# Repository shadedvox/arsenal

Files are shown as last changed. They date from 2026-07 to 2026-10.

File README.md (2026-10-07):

# Arsenal

A 6-DOF robotic arm built around a custom STM32 motor controller, closed-loop steppers, and a distributed ROS control stack. The project moves through four stages: electronics, mechanical build, firmware/control integration, and final assembly with the end effector.

---

## Stage 1 — Voxboard (electronics)

Voxboard is a custom 4-layer PCB motor controller built to drive all six joints of the arm from a single board. It replaces an earlier ESP32 + 28BYJ-48 stepper setup with a proper closed-loop system capable of real position feedback and real-time multi-axis control.

**Core architecture**
- STM32F446RET6 (LQFP64, 180MHz Cortex-M4 with FPU) handles all real-time motor control
- Raspberry Pi 3B+ runs inverse kinematics (ikpy) and talks to the STM32 over UART
- 3x TMC2209 drivers for the NEMA17 motors at roll, pitch, and yaw
- 3x TMC5160 drivers for the NEMA23 motors at elbow, base and shoulder
- 10 to 20:1 cycloidal gearbox on every joint, with an MT6835 absolute magnetic encoder at each gearbox output shaft for true closed-loop position feedback, no homing required on power-up

**Connectivity**
- CAN (for the end-effector node), USB, dual SPI (encoders + TMC5160s), triple UART (TMC2209s + RPi), I2C, SWD for debug

**Power**
- Single 24V input via XT60, reverse-polarity and surge protected, stepped down to 5V (buck) and 3.3V (LDO) for logic
- USB VBUS backup path with ideal-diode OR-ing, so the board can run off USB power alone for debug/bring-up

**Project Files & Schematics :** [\Stage1 - STM\voxboard](https://github.com/shadedvox/arsenal/tree/main/Stage1%20-%20STM/voxboard)

**Status: design completed - fabrication pending**

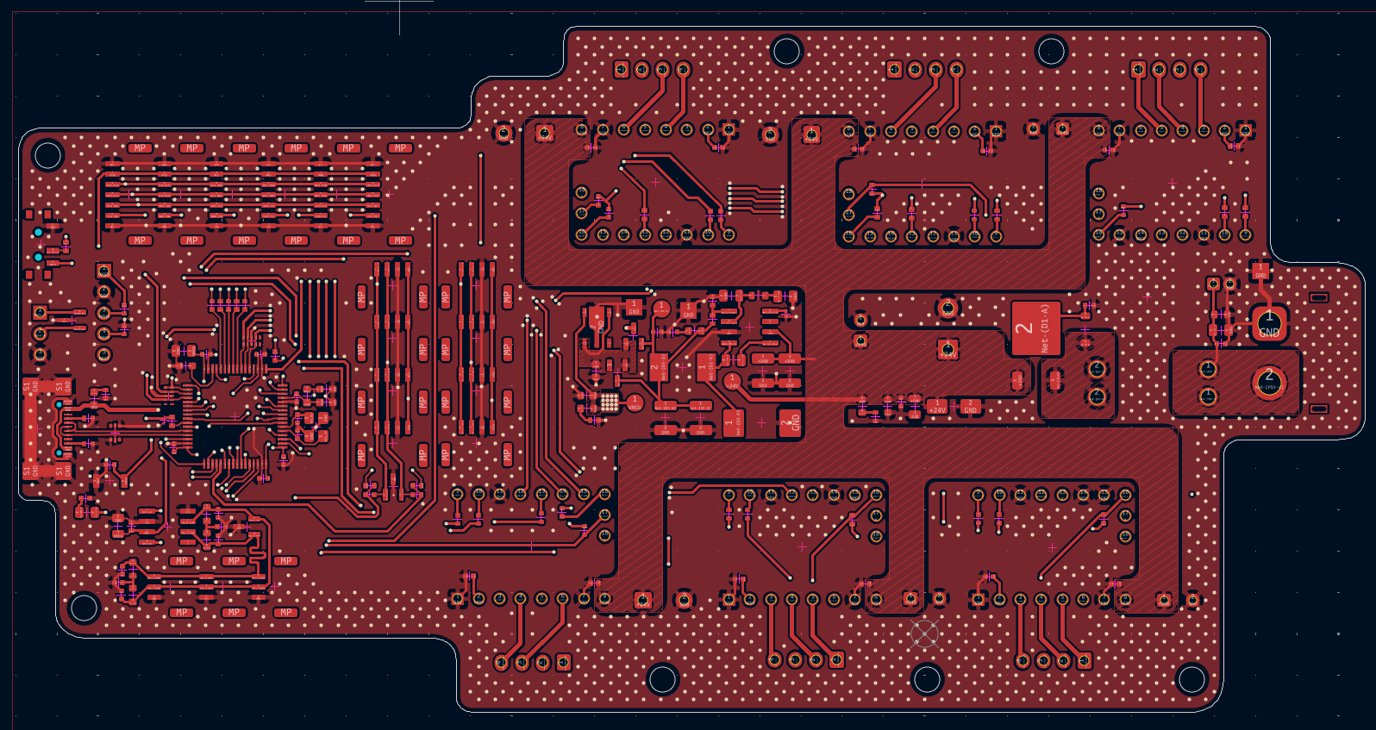
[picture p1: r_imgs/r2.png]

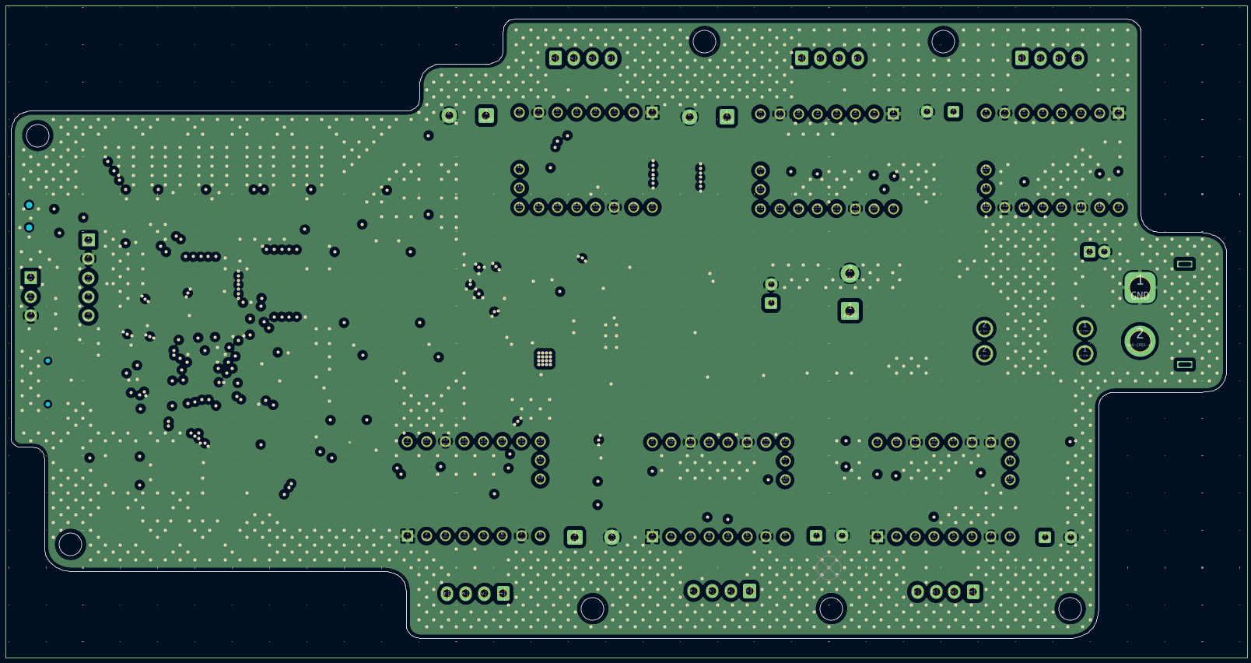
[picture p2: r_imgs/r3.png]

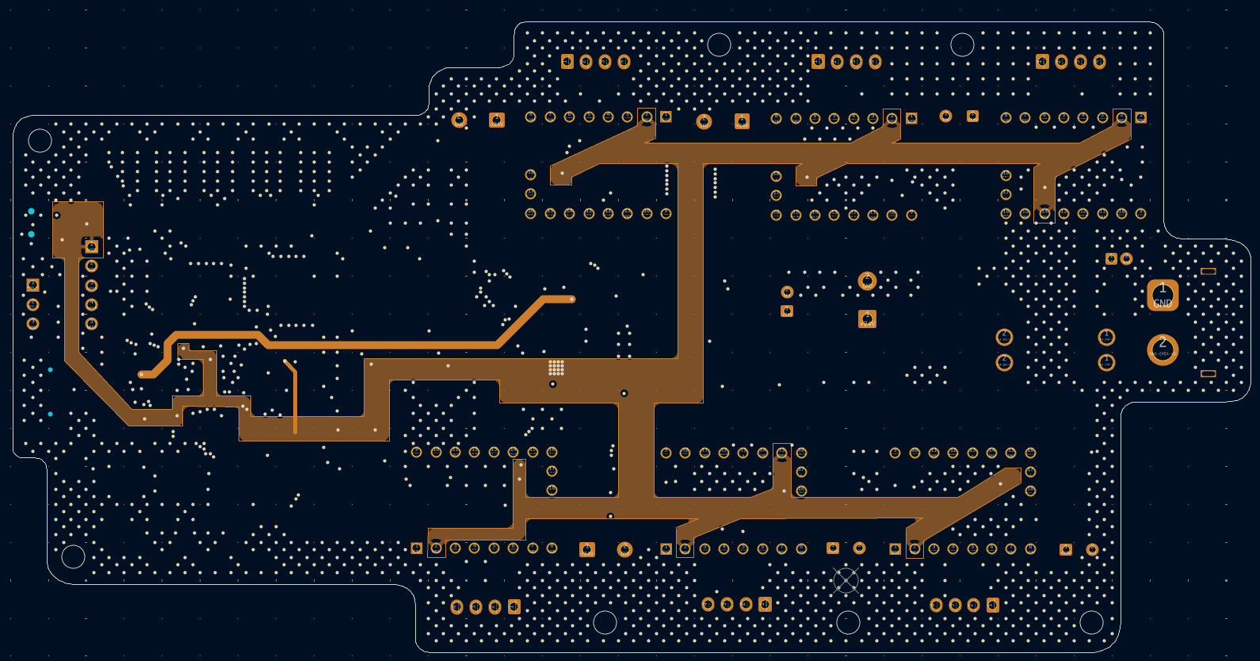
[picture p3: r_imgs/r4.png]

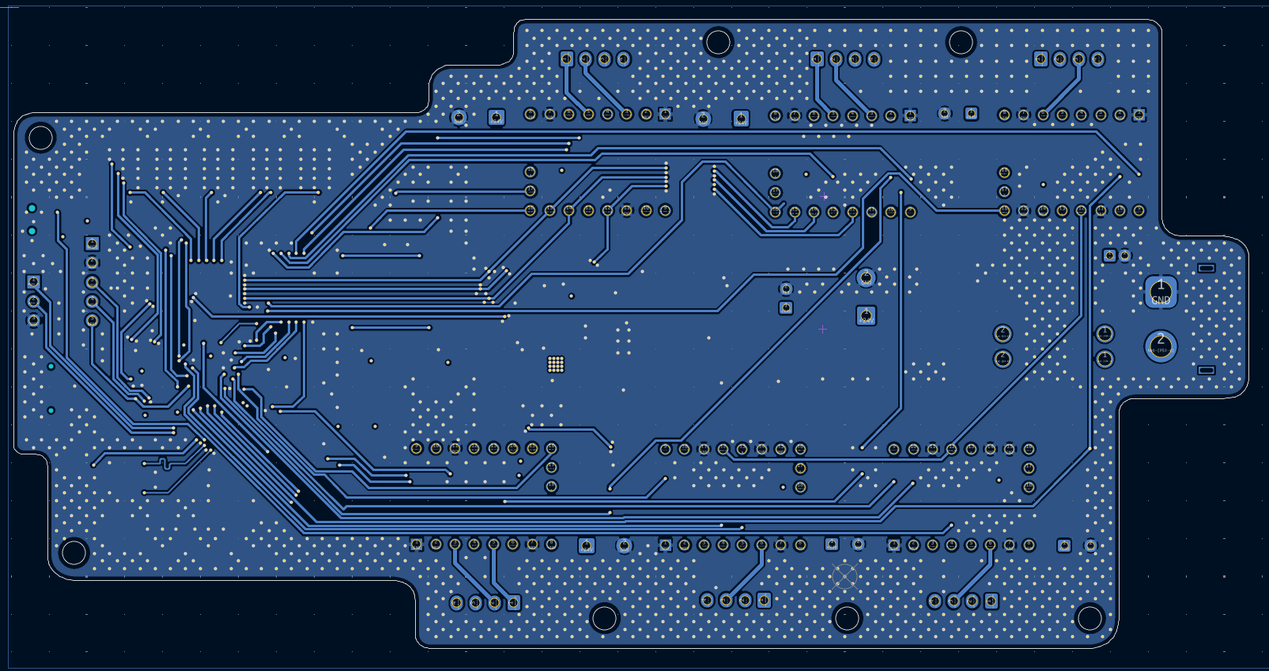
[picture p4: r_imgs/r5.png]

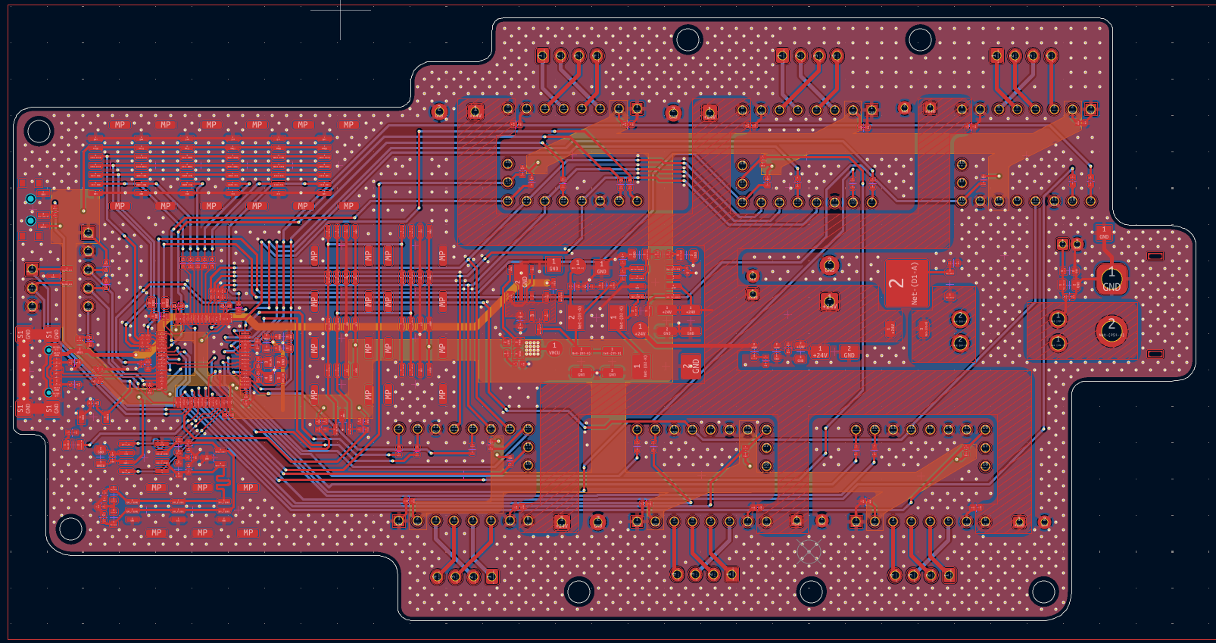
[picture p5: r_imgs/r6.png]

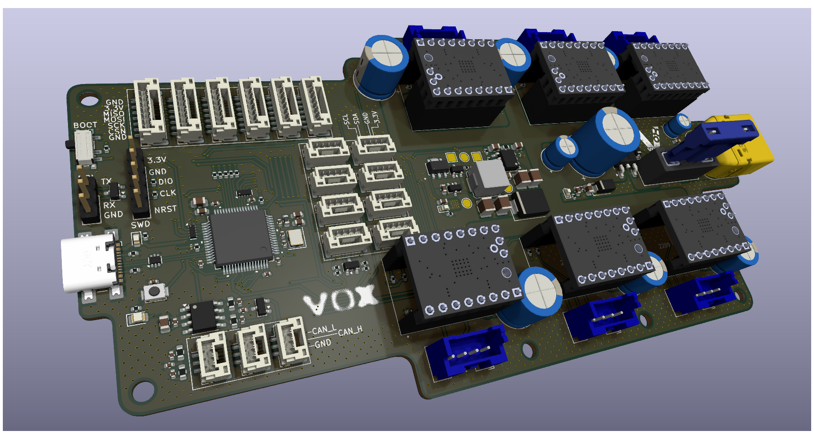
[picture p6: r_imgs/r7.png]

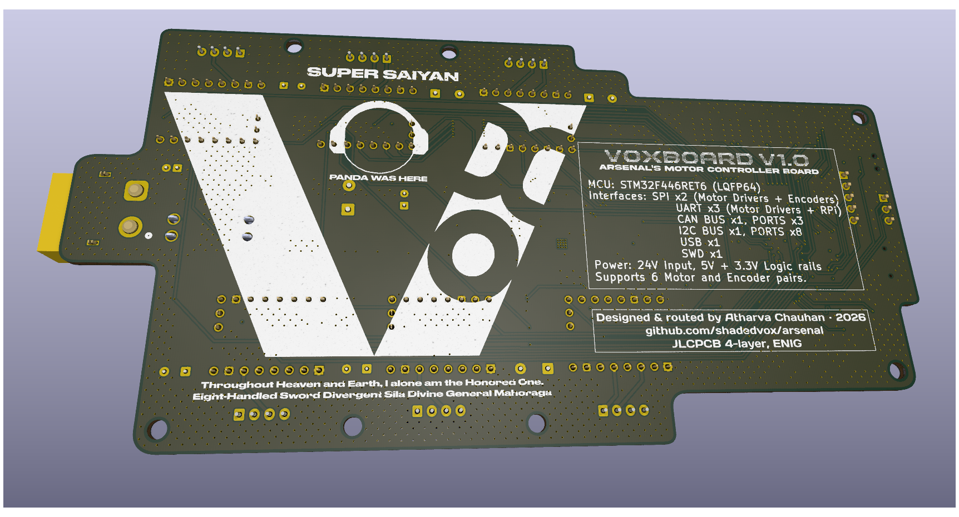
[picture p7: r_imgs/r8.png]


---

## Stage 2 — Mechanical build

3D-printed cycloidal gearboxes and joint assemblies, structural frame for the arm.

**Status: in progress**

---

## Stage 3 — Firmware & control

Real-time motor control on the STM32, distributed ROS architecture with MoveIt running on the Pi/PC side.

**Status: in progress**

---

## Stage 4 — Integration & end effector

Final assembly, end-effector design, and full-arm bring-up.

**Status: in progress**

---

*© 2026 Atharva Chauhan, Vox*

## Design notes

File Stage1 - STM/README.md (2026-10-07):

# Voxboard

A custom 4-layer motor controller board for a 6-DOF robotic arm, built around an STM32F446RET6. It drives six stepper motors with closed-loop magnetic encoder feedback, talks to a Raspberry Pi for inverse kinematics, and exposes CAN, I2C, and USB for future expansion.

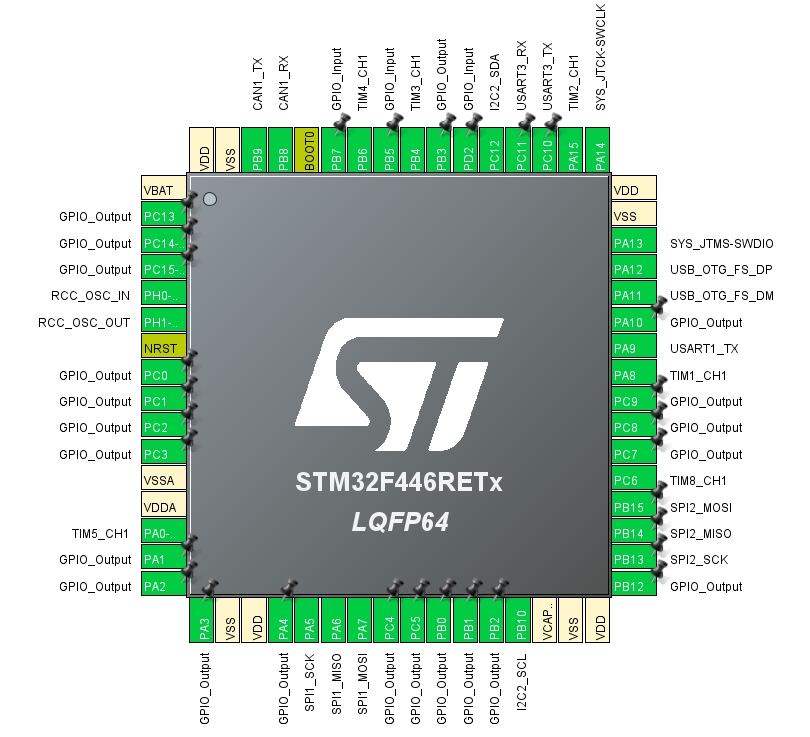
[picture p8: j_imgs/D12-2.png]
Pinout

Schematics

---

## Core MCU

- STM32F446RET6, Cortex-M4 running at 180MHz off an 8MHz crystal
- Standard ST decoupling scheme on VDD/VBAT and VDDA, per-pin 100nF caps plus bulk capacitors
- NRST push button (internal pull-up, no external needed) and a BOOT0 slide switch
- 5-pin SWD header for programming via ST-Link
- Heartbeat LED for status indication

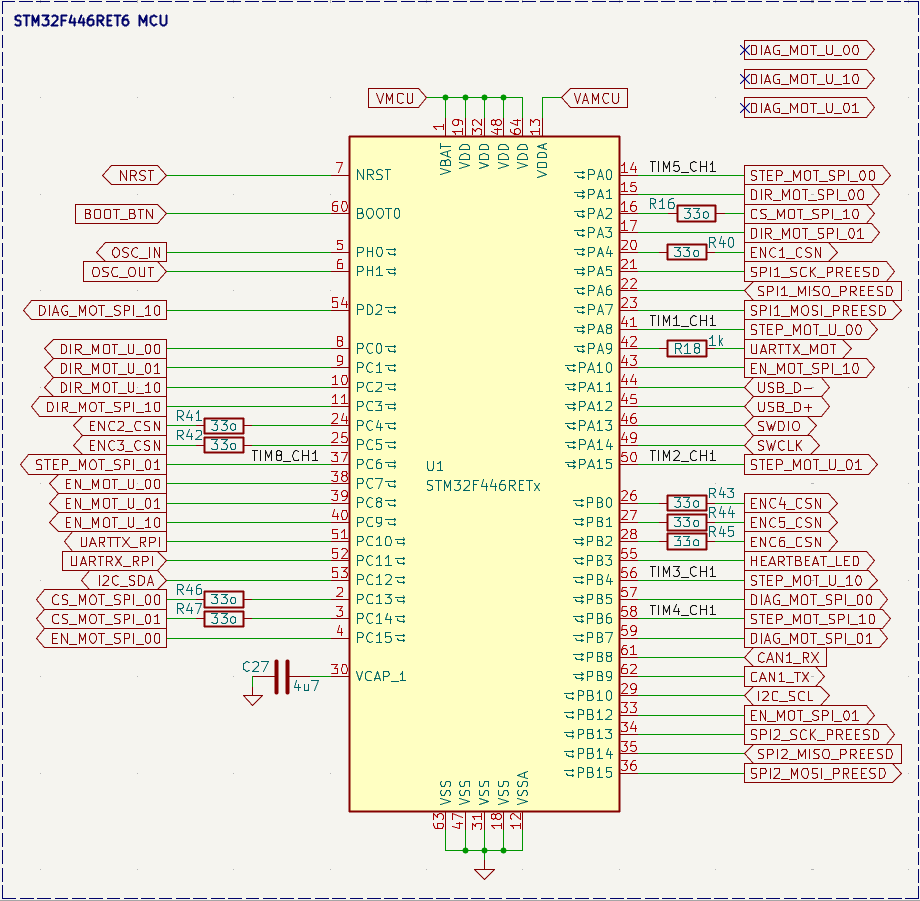
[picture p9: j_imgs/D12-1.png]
MCU


---

## Power

24V enters through an XT60 connector and feeds a back-EMF and filtering network before splitting off to the motors directly. A buck converter (TPS54331) steps 24V down to 5V, feeding an LDO that regulates the final 3.3V logic rail. Running two stages instead of a single 24V-to-3.3V converter keeps the logic rail clean and low-noise.

A P-MOSFET and Schottky diode pair handles priority between the buck output and USB VBUS, so the board always runs off the battery when it's present and only falls back to USB power for programming when it isn't.

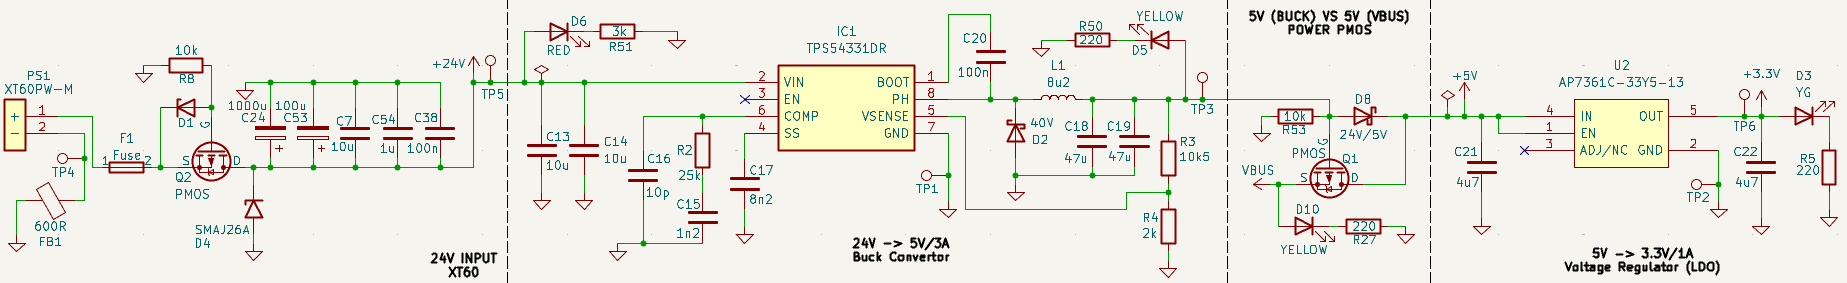
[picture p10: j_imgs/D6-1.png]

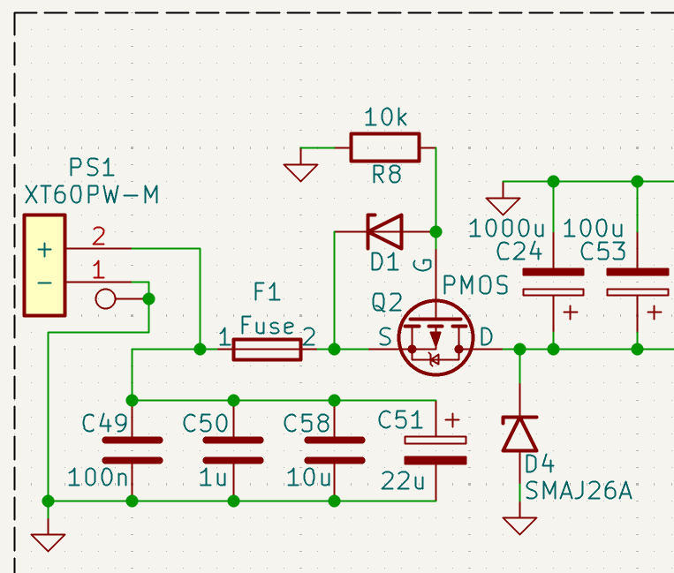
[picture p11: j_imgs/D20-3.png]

VBUS priority circuit

Status LEDs indicate activity on each rail: red for 24V, yellow for VBUS/5V, yellow-green for 3.3V.

---

## Motor drivers

Six motors in total: three NEMA17s (roll, pitch, yaw) driven by TMC2209s over single-wire half-duplex UART, and three NEMA23s (base, shoulder, elbow) driven by TMC5160s over a shared SPI bus. The NEMA23s sit at the joints carrying the highest load.

Each TMC2209 gets an address set through its MS1/MS2 pins, allowing multiple drivers to share one UART line. STEP, DIR, and EN are wired per driver, with series resistors for current limiting. DIAG is only connected on the TMC5160s, since those joints need it most and GPIO budget is tight.

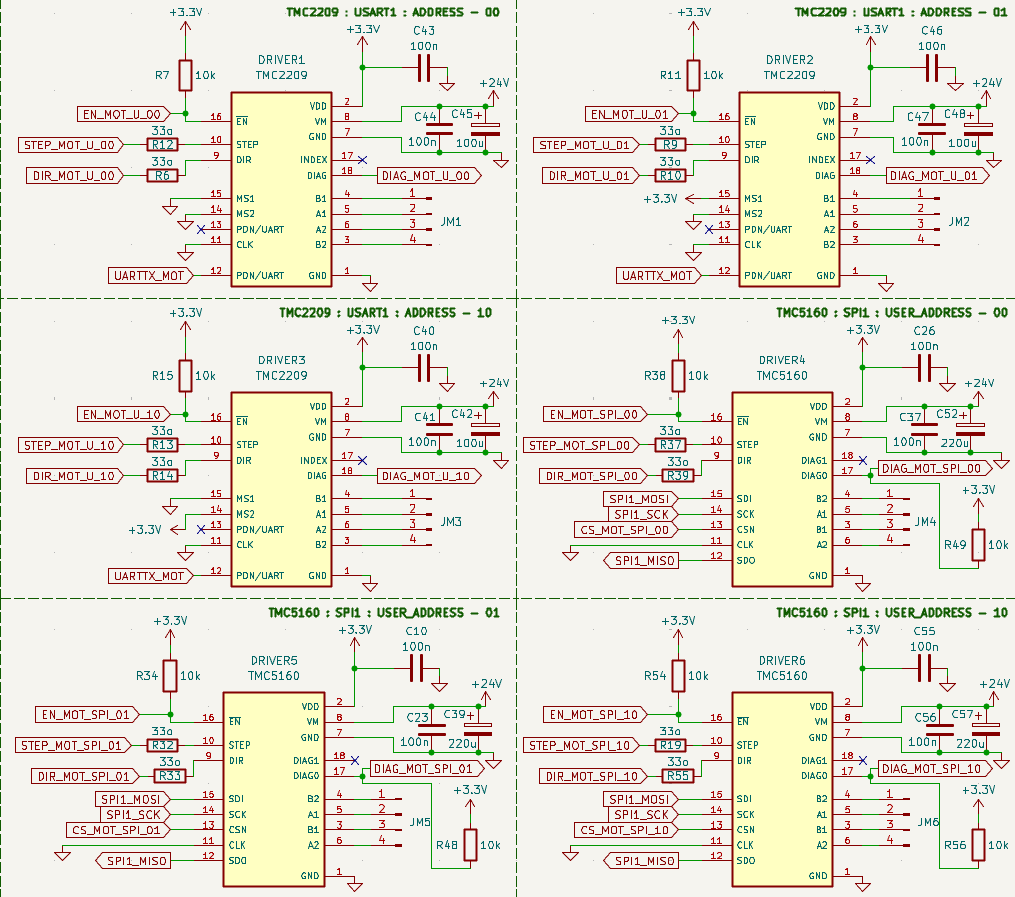
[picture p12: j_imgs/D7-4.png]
Motor driver circuit


Motors connect through JST-XH connectors mounted directly on the board.

---

## Encoders

Six MT6835 magnetic encoders, one per joint, provide absolute position feedback at the gearbox output shaft. They share a single SPI bus. CAL_EN is tied to ground since calibration is triggered through software instead.

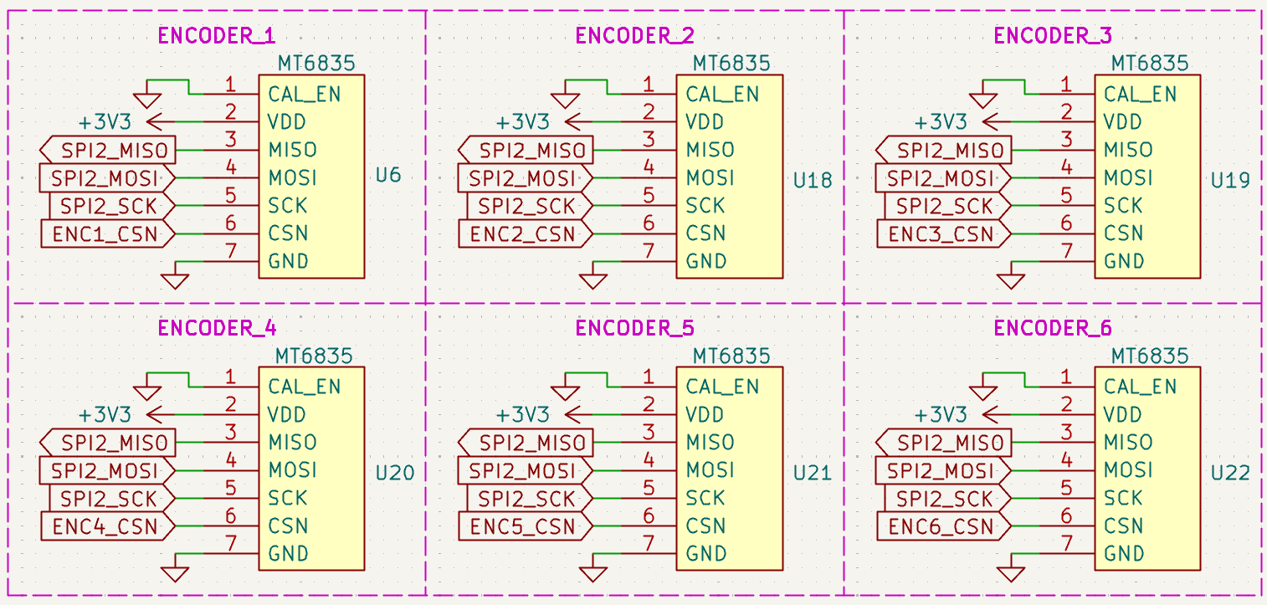
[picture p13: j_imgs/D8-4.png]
Encoder circuit


---

## CAN bus

An SN65HVD230DR transceiver gives the board a CAN interface, mainly intended for connecting an end-effector controller later on. Includes end-termination and ESD protection placed right at the connector.

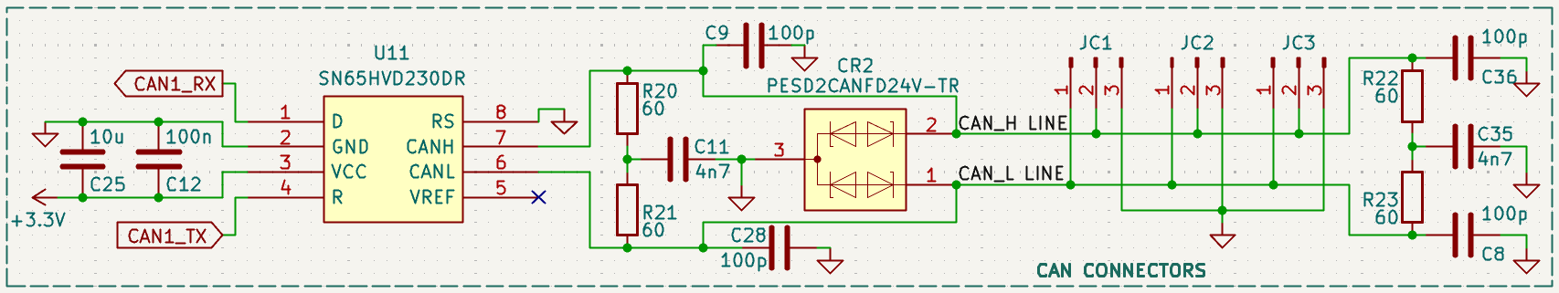
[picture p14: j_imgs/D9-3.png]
CAN bus circuit


---

## I2C

A couple of JST-GH connectors broken out for I2C, left open for future sensors. Same ESD protection approach as the rest of the board's external connectors.

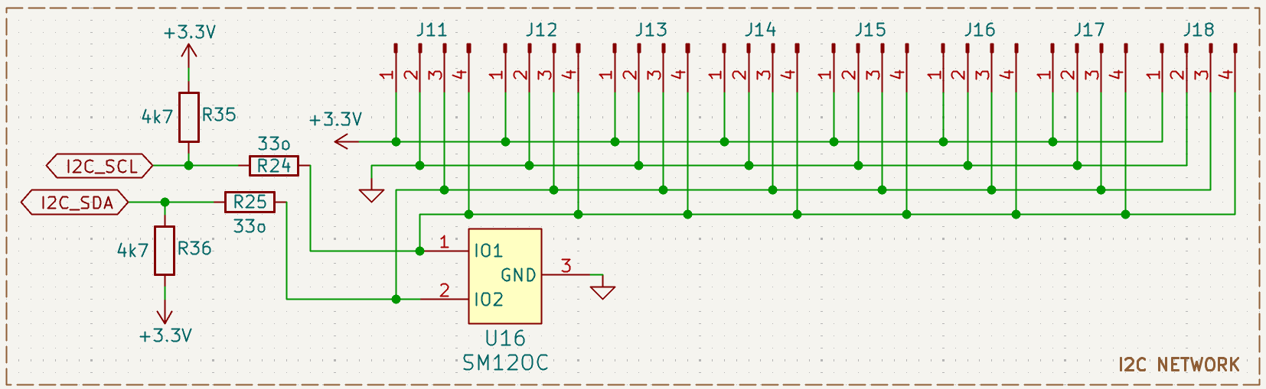
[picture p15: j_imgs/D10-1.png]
I2C connectors


---

## USB

A USB-C 2.0 connector with ESD protection on the D+/D- lines, used purely for programming and debug, not for powering the whole system under normal operation.

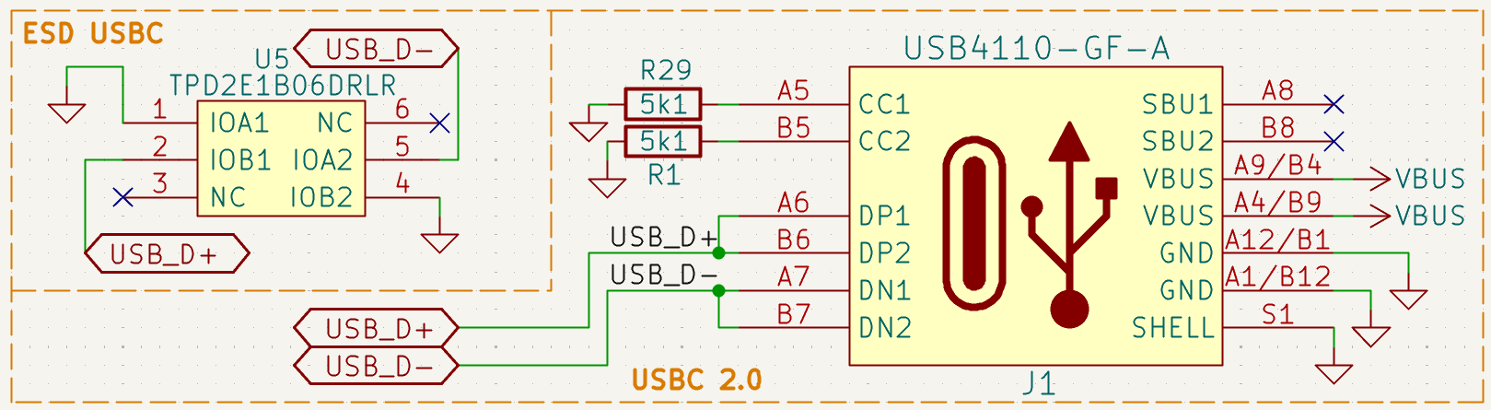
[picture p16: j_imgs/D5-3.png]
USB-C circuit


---

## ESD protection

Connectors that reach off-board (USB-C, CAN, RPi UART, I2C) get ESD protection right at the connector, stopping any transient before it reaches the rest of the circuit. Buses that stay entirely on-board (encoder SPI, driver SPI, TMC2209 UART) get their ESD protection near the MCU instead, guarding the chip pins directly.

---

## Layout and routing

4-layer stackup: signal, ground, 3.3V power, signal. The ground plane is a single unified pour, motors and logic share it, with noise managed through tight decoupling and via stitching rather than a split plane.

High-current traces run as fill zones rather than individually routed tracks, since a shaped pour handles current distribution far more cleanly for the 24V rail. All vias are standard through-hole, 0.4/0.3mm, chosen as JLCPCB's smallest reliably manufacturable size.

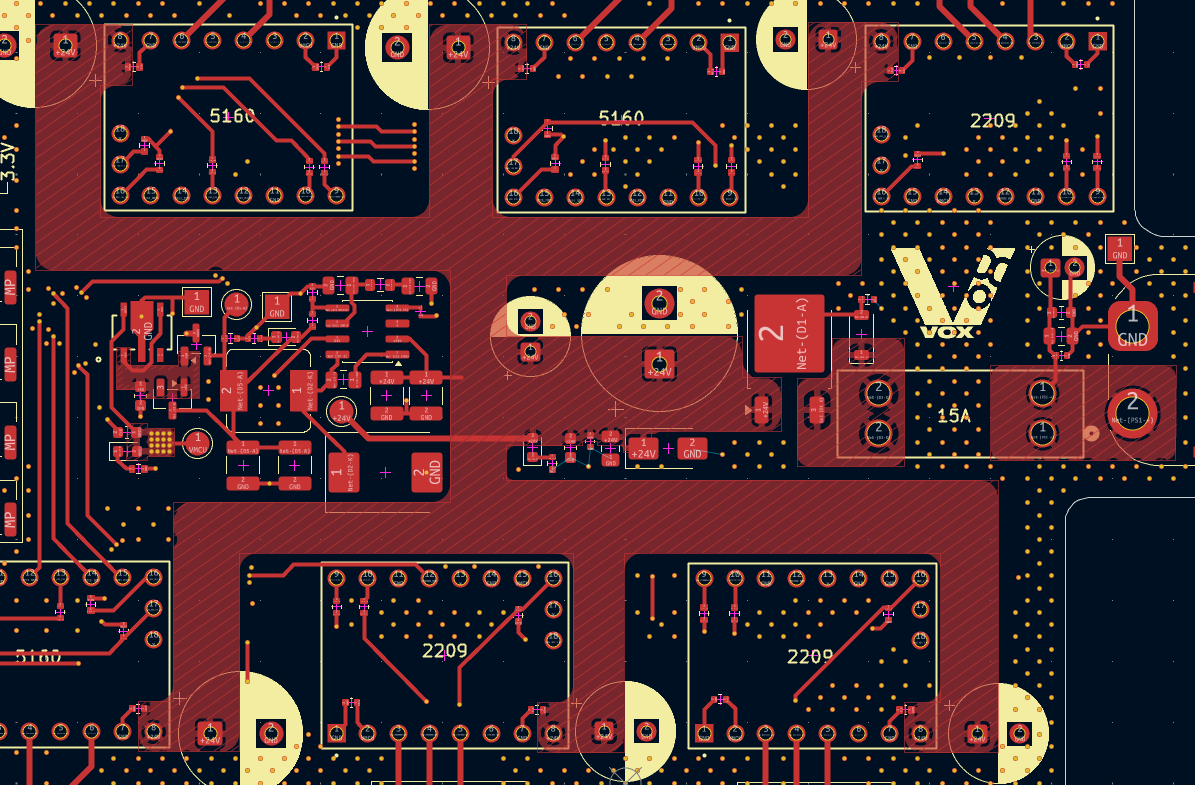
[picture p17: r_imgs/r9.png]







Ground stitching vias run alongside every high-speed signal via to keep return paths short and reduce EMI.

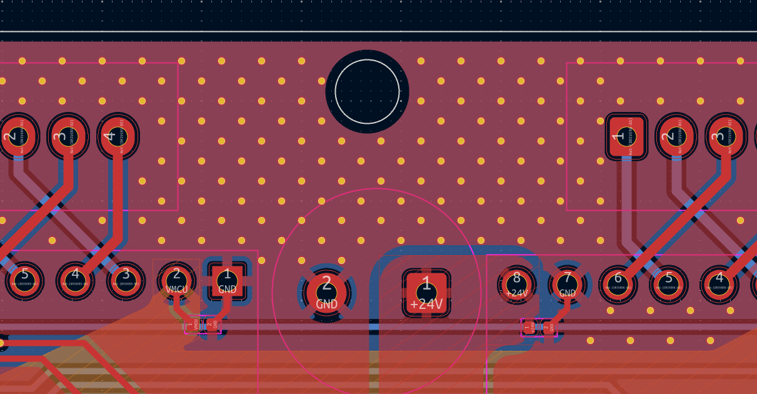
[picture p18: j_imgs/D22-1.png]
Via stitching and ground pours


---

## Final board




Custom 3D models were made in Fusion 360 for parts without existing KiCad models, including the main inductor and the motor driver modules. Silkscreen on the back carries a short board description, designer credit, and a small logo.

---

## BOM

Parts list exported from KiCad and matched to JLCPCB part numbers. Total parts cost as of October 2026: **$263.61 for 2 PCBAs** (excludes PCB fabrication and assembly charges). Full BOM and schematic files live in [`/Stage1 - STM`](https://github.com/shadedvox/arsenal/tree/main/Stage1%20-%20STM).

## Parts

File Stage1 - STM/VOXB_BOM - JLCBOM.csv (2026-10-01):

Comment | Designator | Footprint | JLCPCB Part#(optional)
100nF | C1, C10, C12, C23, C26, C30, C31, C32, C33, C34, C37, C38, C4, C40, C41, C43, C44, C46, C47, C49, C55, C56 | C0402 | C56392
4.7nF | C11, C35 | C0402 | C1538
10uF | C13, C14 | C1210 | C39232
1.2nF | C15 | C0805 | C1714
10pF | C16 | C0805 | C107107
8.2nF | C17 | C0201 | C2168104
47uF | C18, C19 | C1210 | C84494
1uF | C2, C3, C50, C54 | C0603 | C29936
100nF | C20 | C0805 | C1711
4.7uF | C21, C22, C27 | C0603 | C69335
1000uF | C24 | CP_Radial_D12.5mm_P5.00mm | C165529
10uF | C25, C29, C58, C7 | C0805 | C440198
100pF | C28, C36, C8, C9 | C0402 | C1546
220uF | C39, C52, C57 | CP_Radial_D10.0mm_P5.00mm | C19270689
100uF | C42, C45, C48, C53 | CP_Radial_D6.3mm_P2.50mm | C19270686
14pF | C5, C6 | C0402 | C458857
22uF | C51 | CP_Radial_D5.0mm_P2.00mm | C216548
PESD2CANFD24V-TR | CR2 | SOT-23 | C552486
D_Zener | D1 | D_SOD-123 | C74710
YELLOW | D10, D5 | D0603 | C2287
40V | D2 | D_SMC | C72264
YG | D3 | D0603 | C2289
SMAJ26A | D4 | D_SMA | C49370
RED | D6 | D0603 | C2286
YELLOW | D7 | D0805 | C2292
24V/5V | D8 | SOT-23 | C8590
120Ω | FB2 | FB0603 | C12391
TPS54331DR | IC1 | SOIC-8_3.9x4.9mm_P1.27mm | C9865
USB4110-GF-A | J1 | USB_C_Receptacle_GCT_USB4110 | C5143397
Conn_01x04_Pin | J11, J12, J13, J14, J15, J16, J17, J18 | JST_GH_BM04B-GHS-TBT_1x04-1MP_P1.25mm_Vertical | C161692
Conn_01x03_Pin | JC1, JC2, JC3 | JST_GH_BM03B-GHS-TBT_1x03-1MP_P1.25mm_Vertical | C161691
Conn_01x04_Pin | JM1, JM2, JM3, JM4, JM5, JM6 | JST_XA_B04B-XASK-1_1x04_P2.50mm_Vertical | C264994
8.2uH | L1 | L_KOHERELEC_MDA7050_7.3x6.6mm | C5359716
5.1Ω | R1, R29 | R0402 | C25905
33Ω | R10, R12, R13, R14, R16, R19, R24, R25, R32, R33, R37, R39, R40, R41, R42, R43, R44, R45, R46, R47, R55, R6, R9 | R0402 | C25105
10kΩ | R11, R15, R26, R30, R31, R34, R38, R48, R49, R53, R54, R56, R7, R8 | R0402 | C25531
1kΩ | R18 | R0402 | C11702
25kΩ | R2 | R0603 | C2828637
60Ω | R20, R21, R22, R23 | R0603 | C166918
220Ω | R27, R5, R50, R52 | R0402 | C25091
10.5kΩ | R3 | R0402 | C100202
4.7kΩ | R35, R36 | R0402 | C25900
2kΩ | R4 | R0402 | C4109
3kΩ | R51 | R0402 | C25784
SW_Push | SW2 | SW_PUSH_B3U-1000PM | C231329
SW_SPDT | SW3 | SW_SPDT_PCM12 | C49023767
STM32F446RETx | U1 | LQFP64-10x10mm | C69336
SN65HVD230DR | U11 | SOIC-8_3.9x4.9mm_P1.27mm | C12084
TPD4E02B04DQAR | U12, U3 | USON-10_2.5x1.0mm_P0.5mm | C106794
PESD5V0F1BRSFYL | U14 | Nexperia_DSN0603-2_0.6x0.3mm_P0.4mm | C552550
SM12OC | U16, U4 | SOT-23 | C20417175
MT6835 | U18, U19, U20, U21, U22, U6 | JST_GH_BM07B-GHS-TBT_1x07-1MP_P1.25mm_Vertical | C5305068
AP7361C-33Y5-13 | U2 | AP7361C-33Y5-13_SOT89-5_DIO | C460397
TPD2E1B06DRLR | U5 | SOT-666 | C1974127
8MHz | Y1 | Crystal_SMD_3225-4Pin_3.2x2.5mm | C2933033

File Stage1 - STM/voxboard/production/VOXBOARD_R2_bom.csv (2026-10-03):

Designator | Footprint | Quantity | Value | LCSC Part #
C1, C10, C12, C23, C26, C30, C31, C32, C33, C34, C37, C38, C4, C40, C41, C43, C44, C46, C47, C49, C55, C56 | 0402 | 22 | 100n
C11, C35 | 0402 | 2 | 4n7
C13, C14 | 1210 | 2 | 10u
C15 | 0805 | 1 | 1n2
C16 | 0805 | 1 | 10p
C17 | 0201 | 1 | 8n2
C18, C19 | 1210 | 2 | 47u
C2, C3, C50, C54 | 0603 | 4 | 1u
C20 | 0805 | 1 | 100n
C21, C22, C27 | 0603 | 3 | 4u7
C24 | CP_Radial_D12.5mm_P5.00mm | 1 | 1000u
C25, C29, C58, C7 | 0805 | 4 | 10u
C28, C36, C8, C9 | 0402 | 4 | 100p
C39, C52, C57 | CP_Radial_D10.0mm_P5.00mm | 3 | 220u
C42, C45, C48 | CP_Radial_D8.0mm_P3.50mm | 3 | 100u
C5, C6 | 0402 | 2 | 14p
C51 | CP_Radial_D5.0mm_P2.00mm | 1 | 22u
C53 | CP_Radial_D6.3mm_P2.50mm | 1 | 100u
CR2 | SOT-23 | 1 | PESD2CANFD24V-TR
D1 | D_SOD-123 | 1 | D_Zener
D10, D5 | 0603 | 2 | YELLOW
D2 | D_SMC | 1 | 40V
D3 | 0603 | 1 | YG
D4 | D_SMA | 1 | SMAJ26A
D6 | 0603 | 1 | RED
D7 | 0805 | 1 | YELLOW
D8 | SOT-23 | 1 | 24V/5V
DRIVER1, DRIVER2, DRIVER3 | MODULE_TMC2209_5160 | 3 | TMC2209
DRIVER4, DRIVER5, DRIVER6 | MODULE_TMC2209_5160 | 3 | TMC5160
F1 | CONN_3557-2_KEY | 1 | Fuse
FB2 | 0603 | 1 | 120R
IC1 | SOIC-8_3.9x4.9mm_P1.27mm | 1 | TPS54331DR
J1 | USB_C_Receptacle_GCT_USB4110 | 1 | USB4110-GF-A
J11, J12, J13, J14, J15, J16, J17, J18 | JST_GH_BM04B-GHS-TBT_1x04-1MP_P1.25mm_Vertical | 8 | Conn_01x04_Pin
JC1, JC2, JC3 | JST_GH_BM03B-GHS-TBT_1x03-1MP_P1.25mm_Vertical | 3 | Conn_01x03_Pin
JM1, JM2, JM3, JM4, JM5, JM6 | JST_XA_B04B-XASK-1_1x04_P2.50mm_Vertical | 6 | Conn_01x04_Pin
JS1 | PinHeader_1x05_P2.54mm_Vertical | 1 | Conn_01x05_Pin
JU1 | PinHeader_1x03_P2.54mm_Vertical | 1 | Conn_01x03_Pin
L1 | L_KOHERELEC_MDA7050_7.3x6.6mm | 1 | 8u2
PS1 | AMASS_XT60PW-M_1x02_P7.20mm_Horizontal | 1 | XT60PW-M
Q1 | SOT-23 | 1 | PMOS
Q2 | TO-252-2 | 1 | PMOS
R1, R29 | 0402 | 2 | 5k1
R10, R12, R13, R14, R16, R19, R24, R25, R32, R33, R37, R39, R40, R41, R42, R43, R44, R45, R46, R47, R55, R6, R9 | 0402 | 23 | 33o
R11, R15, R26, R30, R31, R34, R38, R48, R49, R53, R54, R56, R7, R8 | 0402 | 14 | 10k
R18 | 0402 | 1 | 1k
R2 | 0603 | 1 | 25k
R20, R21, R22, R23 | 0603 | 4 | 60
R27, R5, R50, R52 | 0402 | 4 | 220
R3 | 0402 | 1 | 10k5
R35, R36 | 0402 | 2 | 4k7
R4 | 0402 | 1 | 2k
R51 | 0402 | 1 | 3k
SW2 | SW_PUSH_B3U-1000PM | 1 | SW_Push
SW3 | SW_SPDT_PCM12 | 1 | SW_SPDT
TP1, TP2, TP4 | TestPoint_Pad_2.0x2.0mm | 3 | TestPoint
TP3, TP5, TP6 | TestPoint_Pad_D2.0mm | 3 | TestPoint
U1 | LQFP64-10x10mm | 1 | STM32F446RETx
U11 | SOIC-8_3.9x4.9mm_P1.27mm | 1 | SN65HVD230DR
U12, U3 | USON-10_2.5x1.0mm_P0.5mm | 2 | TPD4E02B04DQAR
U14 | Nexperia_DSN0603-2_0.6x0.3mm_P0.4mm | 1 | PESD5V0F1BRSFYL
U16, U4 | SOT-23 | 2 | SM12OC
U18, U19, U20, U21, U22, U6 | JST_GH_BM07B-GHS-TBT_1x07-1MP_P1.25mm_Vertical | 6 | MT6835
U2 | AP7361C-33Y5-13_SOT89-5_DIO | 1 | AP7361C-33Y5-13
U5 | SOT-666 | 1 | TPD2E1B06DRLR
Y1 | Crystal_SMD_3225-4Pin_3.2x2.5mm | 1 | 8MHz

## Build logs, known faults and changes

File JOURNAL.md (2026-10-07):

---
title: "ARSENAL — 6-DOF Modular Robotic Arm"
author: "Atharva Chauham"
description: "A 6 DOF arm featuring a custom control-board, running on Inverse Kinematics"
created_at: "2026-05-29"
---

# 2026-05-29: Stage 1 — Custom STM32F446-Based Motor Controller (Dev Board) - DEVLOG1 - RESEARCH

This is my first journal entry for this project. I'm fairly new to dev board designing for STM32, so I needed to get familiar with the MCU itself. It turned out to be quite complicated, but I found resources that made it simpler. First I needed to figure out how my dev board is going to work, basically what goes where and how it all connects.

My board needs an MCU of course, along with all the components needed to support it, then four NEMA 17 motors and their drivers. These four motors will be of different torque ratings: the elbow needs to be the highest rated NEMA 17, while the yaw needs to be the lowest, though this will ultimately be based on availability. Along with these, for the base and shoulder I need two NEMA 23 motors and their TMC5160 drivers. All the motors will have magnetic encoders on them so I can track their rotation accurately. So my board will have two UART connections for the four TMC2209 drivers (NEMA 17), with one UART split for two drivers, and one SPI connection for the two TMC5160 drivers (NEMA 23). The six encoders will also share one SPI connection, and the third SPI will be left open, I might add a display later, though it isn't needed at this stage. I've also been thinking about adding an ESP32 chip, mainly for the combined Wi-Fi, Bluetooth, and especially ESP-NOW, since I could potentially make a controller using joysticks, a screen, and an ESP32 to control the arm myself. I'm still figuring some stuff out for this, since I could make a separate ESP board entirely for wireless connections and hook that up over UART to the Raspberry Pi. I'll figure this out soon. After this research phase, four hours which I forgot to log at the time, I started watching a video on STM32 design by Phil's Lab, which wasq quite helpful. After the schematics part was done, I started reading the application notes for power and USB, and the F446RE datasheet.
The research is hopefully done for now, onto making the schematics.
This reading was recorded via timelapse here: https://lapse.hackclub.com/timelapse/VTKueXd4oU-n

**Total time spent: 6 hours**

# 2026-06-12: Stage 1 — Custom STM32F446-Based Motor Controller (Dev Board) - DEVLOG2 - BASE SCHEMATICS

I started working on the main schematics of the board, starting with the MCU. I connected up the MCU power grid, including the decoupling capacitors, then the clock circuit, all configured using STM32CubeMX.

This took a lot of time since I was simultaneously looking up niche or specific parts on the JLCPCB parts picker. For example, finding my crystal resonator took a while since JLCPCB now refers to crystal resonators simply as "crystals." My clock configuration on the STM32 chip also wasn't auto calculating correctly, and my HCLK, the chip's clock speed, was capped at 16MHz when it can go up to 180MHz. This took a while to figure out since that part is supposed to be automatic, which made it hard to find solutions. After a few tweaks to the configuration, 180MHz was verified using an 8MHz resonator.

Next I'll be working on attaching a USB-C header, then creating the main 24V to 3.3V power circuit, since I plan on using external 24V power that I'll step down using an onboard buck converter. After that I'll work on the connection protocols, the UARTs and SPIs for the drivers. I'll also probably add jumper headers to most of the unconnected GPIOs so I can expand the board's capabilities later on.


**Total time spent: 5 hours**

# 2026-06-13: Stage 1 — Custom STM32F446-Based Motor Controller (Dev Board) - DEVLOG3 - POWER CIRCUITRY - 1

For power, I'm using a 24V input from an external source (wall power adapter) through the XT60 power connector. To run my MCU I had to step this down to 3.3V, or else everything goes up in smoke. For this I made my buck converter onboard, and the circuitry ended up being a lot more difficult than expected.

This is the general application circuit provided in the datasheet of the IC I'm using (TPS54331), and it looks like exactly what I need, but it wasn't quite that simple.
This is a direct 7-28V to 3.3V converter. I could have gone with this, but it usually produces a noisy output, which isn't ideal for a stable operating MCU. So the plan is a 24V to 5V buck stage, then a 5V to 3.3V LDO. The LDO provides the stabilization needed at the output and reduces noise drastically. The issue was I had to wire the buck stage for 24V to 5V. Not a lot changes here, only the compensation network, the voltage divider resistors, and the main inductor, all derivable from formulas in the datasheet.  Sounds straightforward, and it would've been, if not for the 'incomplete' datasheet.

The biggest headache of this entire part was the compensation network, because the datasheet has no reference as to what alpha is, not written anywhere. After assuming alpha to be the gain, which turned out to be true, I found that the datasheet's own calculations for its network did not match up. It gets better: ceramic capacitors experience something called derating, where at higher temperatures and/or voltages their capacitance dips. At 5V, a lot of 10V capacitors become around 30 to 40 percent of their initial value, so a 100uF 10V ceramic becomes a 30 to 40uF capacitor, more than half the capacity lost. This was crucial for my output capacitors since they'd be the ones under load, so I had to go through the entire JLCPCB parts library for capacitors that don't derate as badly at 5V. In the end I settled on a 16V ceramic I found with manageable derating. Many datasheets also don't include the derating curve itself, which is what you need to figure out how much derating occurs at a given voltage. I switched to electrolytic capacitors midway, then needed their ESR, which again was missing from the datasheets. This was by far the most frustrating part of the project so far.

Now I have another problem. I have to wire up the USB-C 2.0 connector, and the issue is that since I have external power, I can't accept VBUS directly. What I also want is for the MCU to stay on when only USB is connected but the battery isn't. So the intended behavior is: battery only, whole system on (motors, drivers, MCU); battery plus USB, whole system on but powered by the battery, with USB used only for programming; USB only, only the MCU on for programming. My plan is to use a mux to monitor both inputs, with VBUS going through an LDO to 3.3V, and main power also at 3.3V. I'll be working on this next.

**Total time spent: 10 hours**

# 2026-06-20: Stage 1 — Custom STM32F446-Based Motor Controller (Dev Board) - DEVLOG4 - USB CIRCUITRY - 1

This is the basic connection of my USB Type-C 2.0 connector with my MCU. It has an ESD protection IC connected to the D+ and D- lines of the connector, since these are high speed USB 2.0 data lines and any ESD event would simply destroy the data.

Now addressing the issue of conflicting VBUS and 5V from the battery. I came up with a simple circuit involving a P-MOSFET, though I'm quite skeptical about how well this works. I started out with simple diode ORing, but I ran into a distinctive issue: when both inputs are connected, whichever side has the higher voltage wins and passes through. Neither of these lines is exactly 5V. VBUS especially is very fluctuating, and my buck output also wouldn't be exactly 5V, I estimate it to be anywhere between 4.8 and 4.9V. So it's possible that VBUS sometimes overpowers the 5V rail and pushes through. Since my goal is to always prioritize the buck output, I chose a PMOS circuit that always prioritizes the buck output over VBUS.


**Total time spent: 2 hours**

# 2026-06-21: Stage 1 — Custom STM32F446-Based Motor Controller (Dev Board) - DEVLOG5 - USB CIRCUITRY - 2

The first issue I addressed was that my symbol for the USB connector, which I had obtained from KiCad itself, was wrong. It was missing the double D+ and D- pins and only had a single CC pin. My guess is it was made to work in only a single orientation, which goes against the USB-C design. So I fixed that with my own symbol for a specific USB-C jack, the USB4110-GF-A.


I also swapped out my ESD chip since I looked at the footprint and it was going to be very hard to route under, as the chip was very, very small. I fixed the rest of the connections as per the new jack.

The main time consumer here was the 5V/VBUS conflict. My last circuit would not have worked, since it did not actually address my "5V buck priority" requirement at all. So in the improved circuit I added a Schottky diode across the gate and the drain. Whenever the 5V buck line is live, it slips past the diode, and since the diode connects the drain and the gate, the PMOS turns off, blocking VBUS.

I've also finalized my encoder choice for the drives to be installed. I've settled on the MT6835, a 21-bit magnetic encoder. My earlier choice was the AS5048A, a 14-bit encoder, but I could not find any marketplace where that was available in India. My latest choice is not only available on Robu, it's also higher resolution.


**Total time spent: 4 hours**

# 2026-06-22: Stage 1 — Custom STM32F446-Based Motor Controller (Dev Board) - DEVLOG6 - POWER CIRCUITRY - 2


The main time consumer this time around was the problem of noise. I had done a pretty decent job of isolating noise earlier, but there were some key blind spots. My PCB, as of now, is meant to be stacked as SIG-GND-POW-SIG, and the ground plane is supposed to be a simple copper pour. This works better since the inner layers use the lighter 0.5oz copper, and having an entire copper plane helps with current distribution and gives very low resistance. This does mean the motors and the logic share the same ground, so noise from the motors travels into the ground plane.
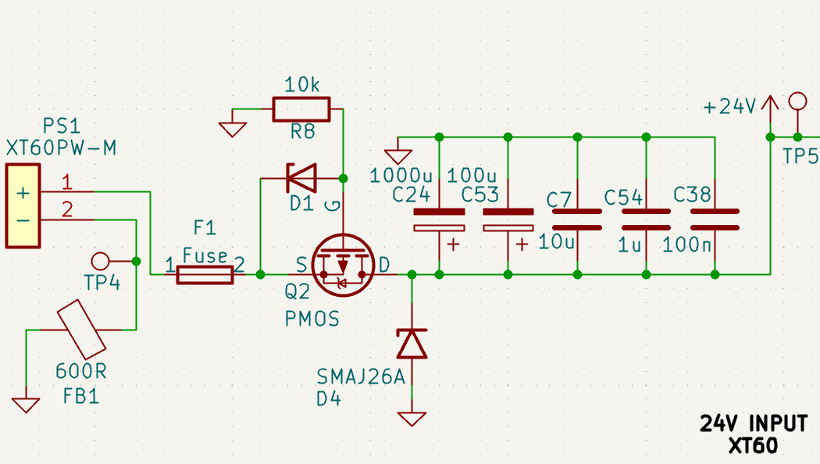
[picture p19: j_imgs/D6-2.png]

I attached 5 decoupling capacitors to the 24V rail to filter out as much of that noise as possible, covering the maximum range of frequency I could, along with bulk decoupling capacitors near the motor drivers. There is also a ferrite bead connecting the connector to the main ground plane. For now, although it isn't perfect, I'd say it's adequate. I will of course be changing some things as I route.
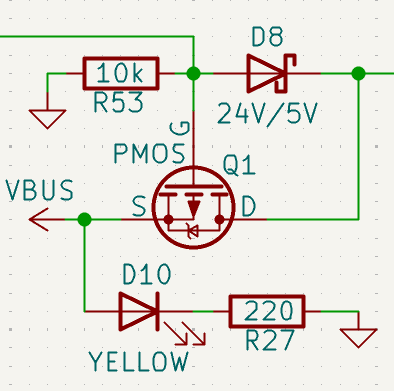
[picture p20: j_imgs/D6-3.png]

This 5V/VBUS conflict circuit has now also been added to the power rail itself.
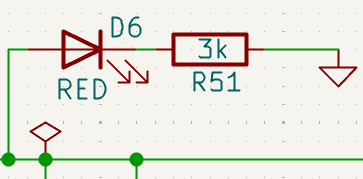
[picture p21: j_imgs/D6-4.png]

I've also added LEDs like this to indicate the activity of several power lines: red for 24V, yellow for both VBUS and 5V (two LEDs indicating the same nominal power level of ~5V), and yellow-green for 3.3V.
I will now be working on the Motor Drivers.

**Total time spent: 5 hours**

# 2026-06-23: Stage 1 — Custom STM32F446-Based Motor Controller (Dev Board) - DEVLOG7 - MOTOR DRIVERS

I will be using 6 motors: 3 NEMA 17s and 3 NEMA 23s. The reasoning behind this distribution is that the NEMA 23s are placed at the base, shoulder, and elbow. The arm has six degrees of freedom, starting from the bottom: base, shoulder, elbow, roll, pitch, yaw. The base, shoulder, and elbow are the joints requiring the most load-bearing capacity, with the shoulder under the most load overall. To control these motors, I'm using [TMC2209](https://global.bttwiki.com/TMC2209.html) drivers for the NEMA 17s and [TMC5160](https://global.bttwiki.com/TMC5160T%20Pro%20V1.0.html) drivers for the NEMA 23s. Since we're only controlling NEMA motors, we could technically use either driver for either motor, but the TMC2209 is widely considered the best purpose-built driver for NEMA 17s, with the TMC5160 being overkill for that role. Similarly, for the NEMA 23s, the TMC5160 is generally considered the better overall pick.
So that's 3 TMC2209s and 3 TMC5160s.
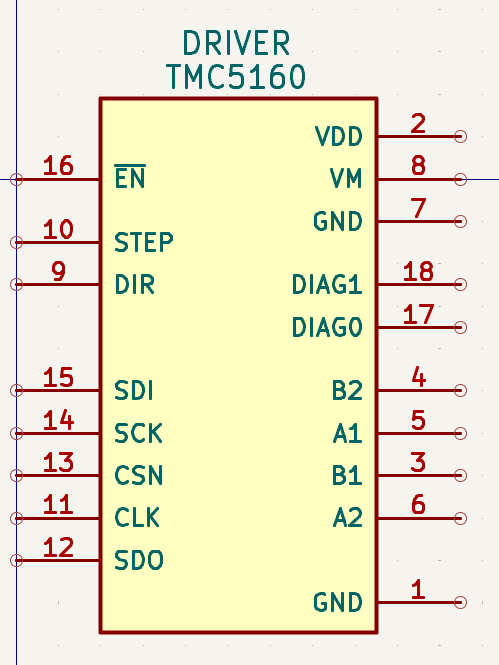
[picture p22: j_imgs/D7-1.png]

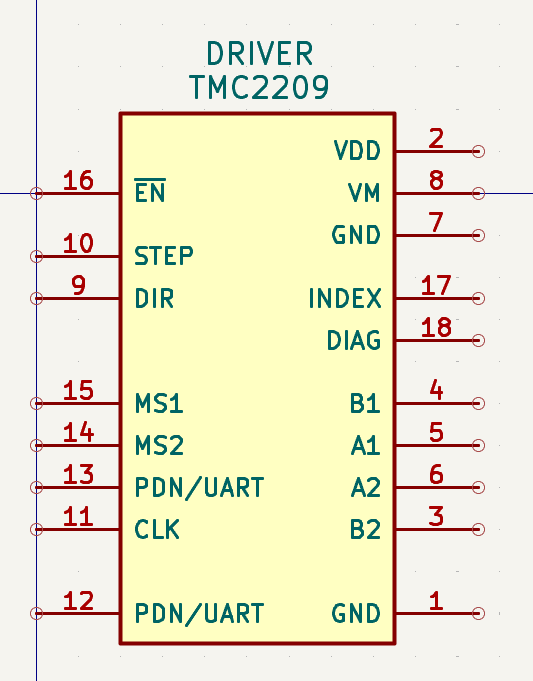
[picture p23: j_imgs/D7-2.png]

These are the symbols I've used for these drivers. Since they're off-the-shelf modules, the footprint is basically just holes for female 2.54mm pitch pin headers.
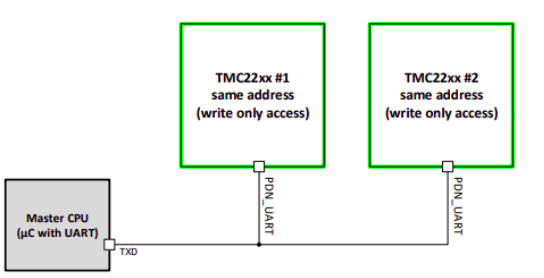
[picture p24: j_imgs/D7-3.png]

A bit on how these drivers function: the TMC2209 uses UART to communicate with the MCU. Since the motor driver is primarily meant to receive commands, I'm using the single-wire (half-duplex) UART mode, connecting only the line needed to transmit commands. An interesting feature of these drivers is that up to four of them can share a single UART line. The MS1 and MS2 pins act as address pins, and setting them high or low in different combinations assigns each driver a UART address. The address is set as a two-bit value, with MS2 as the high bit and MS1 as the low bit.
If both pins are grounded, both bits are 0, giving address 00.
If MS1 is tied to VCC and MS2 is grounded, MS1 reads 1 and MS2 reads 0, giving address 01.
The remaining two combinations give addresses 10 and 11, allowing up to four drivers on a single UART line. Since I'm only using 3 drivers, a single half-duplex UART line is sufficient. A couple of other things worth mentioning: the DIAG pin, common to both driver types, is a diagnostics pin that signals the MCU if something is wrong. This needs to be wired to a GPIO if it's going to be used, and due to a tight pin budget, I'm only connecting the DIAG pin on the TMC5160 drivers, the ones for the base, shoulder, and elbow, since these are the joints carrying the most load. The other main shared pins are EN, STEP, and DIR.
EN is the enable pin, essentially the on/off switch for the driver. STEP is the pulse input, where a single pulse moves the motor one step forward. DIR is the direction pin, and setting it HIGH or LOW determines whether the motor spins clockwise or counterclockwise.
The TMC5160 uses SPI, with four pins for communication that give access to the drivers' smart features and allow software control. These four pins are MOSI, MISO, CSN, and SCK. Connecting the motors to the drivers is its own task, since the motors have four-wire, non-center-tapped inputs corresponding to the two internal coils. I've added JST-VH connectors directly on the main board so the motors can plug straight in.
I've also added decoupling capacitors on the VMOT line, the driver's 24V input, along with 33 ohm resistors on the STEP and DIR lines of each driver and on the CSN line of the TMC5160s, just to limit current. The DIAG pins on the TMC5160s require an external pull-up, which has also been added.

This is the finished motor driver circuit. Next I'll be wiring up the encoders.
PS: I've been using global labels to keep the overall circuit neat and easy to read.

**Total time spent: 7 hours**

# 2026-06-24: Stage 1 — Custom STM32F446-Based Motor Controller (Dev Board) - DEVLOG8 - MAGNETIC ENCODERS

I am using [MT6835](https://robu.in/product/mt6835-magnetic-encoder-module-pwm-spi/) magnetic encoders for the arm.
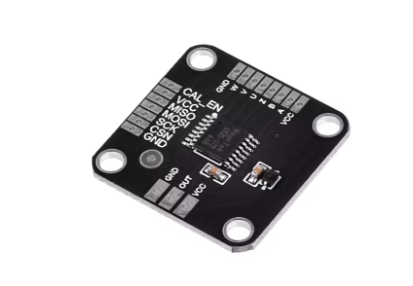
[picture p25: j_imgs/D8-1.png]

Magnetic encoders are essentially smart direction detectors: all they do is measure the change in direction of a magnetic field. A diametric magnet, meaning a magnet with opposite poles across a diameter, is placed coplanar above the chip, leaving just a tiny gap of about 1mm.

The chip detects changes in the direction of the magnetic field produced by the magnet above it. The higher the resolution, the smaller the change in angle it can detect. A 21-bit encoder like this gives an angular precision of about 0.0001717 degrees.
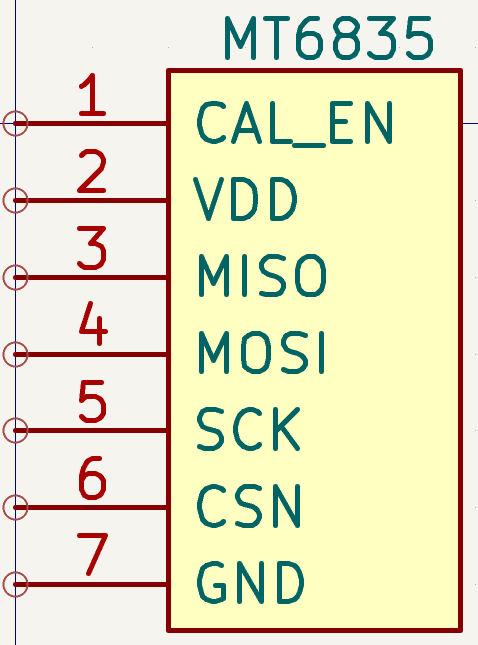
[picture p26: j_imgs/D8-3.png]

The MT6835 uses normal 4 pin SPI to communicate with the board. It has a CAL_EN pin, the calibration enable pin, which triggers auto-calibration mode when pulled high. Since I'm using SPI, I can trigger calibration through software instead, so grounding this pin is the right choice. All six encoders, one for each joint, are connected to the same SPI bus.

The encoders will be placed in front of the gearboxes I'll be using on the NEMA motors, since the gearbox output will be the actual driving force being measured.

**Total time spent: 1 hour**

# 2026-06-25: Stage 1 — Custom STM32F446-Based Motor Controller (Dev Board) - DEVLOG9 - CAN BUS

I've decided to add a CAN bus to the board, mainly for expansion purposes. For example, I could connect the end-effector, a gripper or claw, to any simple MCU and wire that system up to this CAN bus. I had also been considering whether I'd ever need to add a camera to automate the arm, but if that happens, I'd wire the camera directly to the Raspberry Pi instead, since CAN buses are far too slow for video data.
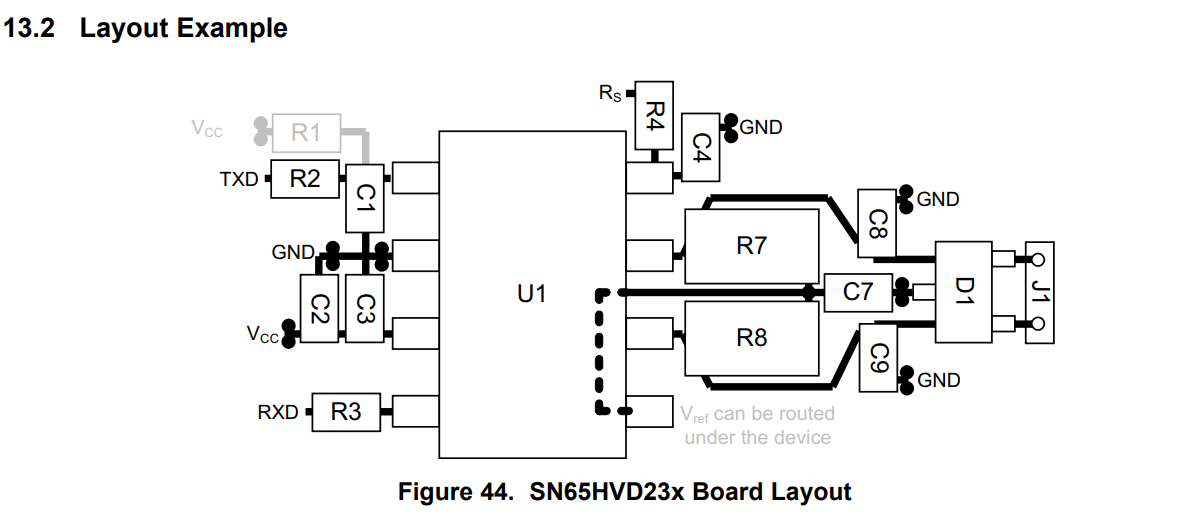
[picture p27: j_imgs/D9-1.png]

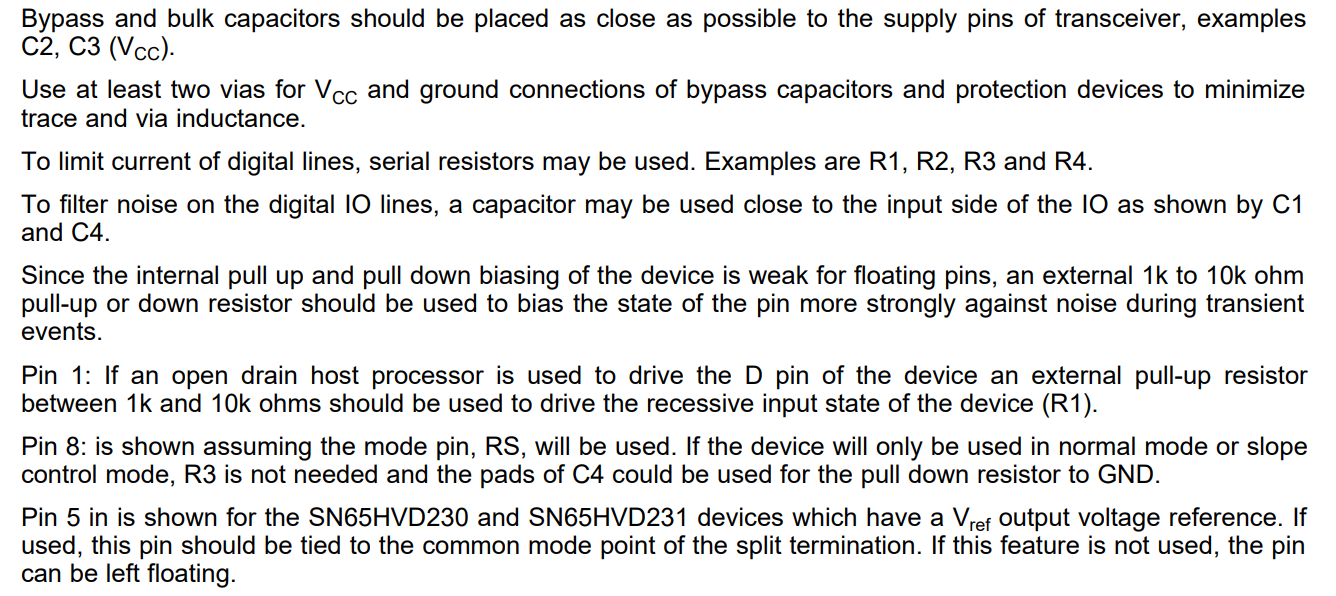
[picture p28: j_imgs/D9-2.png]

For this, I'm using an SN65HVD230DR CAN transceiver IC, and I'm essentially replicating the circuit shown above. I'll be adding multiple headers and the end-termination network directly on this board so I don't have to worry about that later. I've also been adding ESD protection to all my components, but most of them are closer to the MCU, so I'll cover that in a later journal. Here, I've added an ESD chip near the connectors, since that's where any surge should be stopped. It took a while and several iterations to figure out the end-termination placement, but this is the finished circuit.

Also, on this board I'm not using standard pin headers, except for the Raspberry Pi UART connection. I need secure, reliable connectors, so I've been using JST connectors. For these headers I've used JST-GH connectors.

**Total time spent: 3 hours**

# 2026-06-26: Stage 1 — Custom STM32F446-Based Motor Controller (Dev Board) - DEVLOG10 - I2C BUS

This is a short one. I've added some I2C connectors just to add support for any sensors I might add in the future, since it doesn't cost much. Many sensors on the market run on I2C, so having a few connectors for that just makes my board a bit more flexible.

Again, I've used JST-GH connectors, with an SM12OC ESD chip placed near them. The pinout for these connectors is VCC-GND-SDA-SCL. Most of my time in these devlogs is spent finding the right components on JLCPCB. Like with the power circuitry, I just couldn't find the right parts: some capacitors had bad derating, some inductors weren't good enough. Another big time consumer is reading through datasheets only to find out the part doesn't actually fit my needs. But with this done, I'm approaching the final stages of the schematics.

**Total time spent: 1 hour**

# 2026-06-26: Stage 1 — Custom STM32F446-Based Motor Controller (Dev Board) - DEVLOG11 - MCU ESSENTIALS

This devlog covers components and connections essential to the MCU.
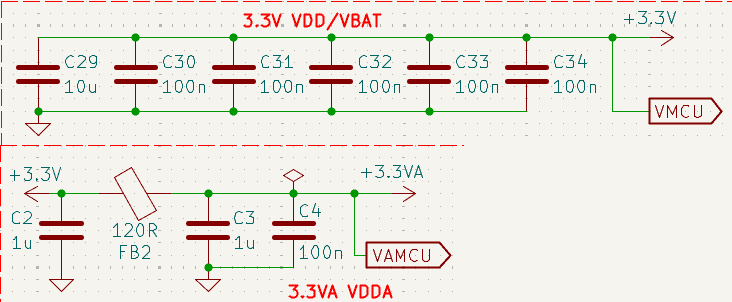
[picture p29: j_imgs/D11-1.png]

These are the decoupling rails for 3.3V and 3.3V analog (VDDA). This follows ST's documentation: one 100nF capacitor per VDD/VBAT pin, plus one bulk decoupling capacitor. The same applies to VDDA, but with an additional bulk capacitor for extra filtering and a ferrite bead connecting the two 3.3V lines.

These are the schematics for the NRST and BOOT button. The BOOT button is a slider switch, and NRST is a push button. NRST already has an internal pull-up, so no external one is required.
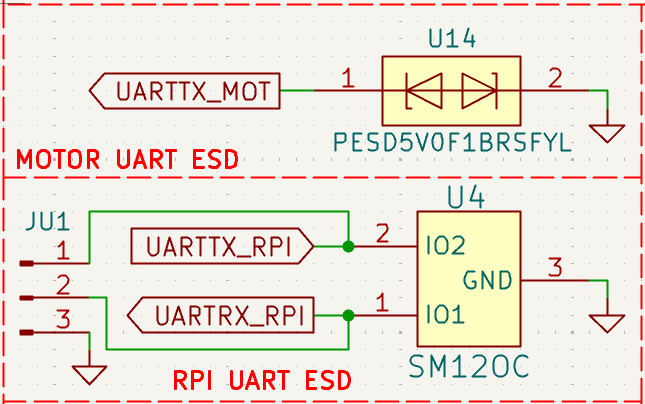
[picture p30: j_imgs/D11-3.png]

These are the MCU's ESD/UART connections. An ESD chip is placed near the MCU for the UART line going to the drivers, and another ESD chip is placed near the three-pin header for the UART connection to the Raspberry Pi.
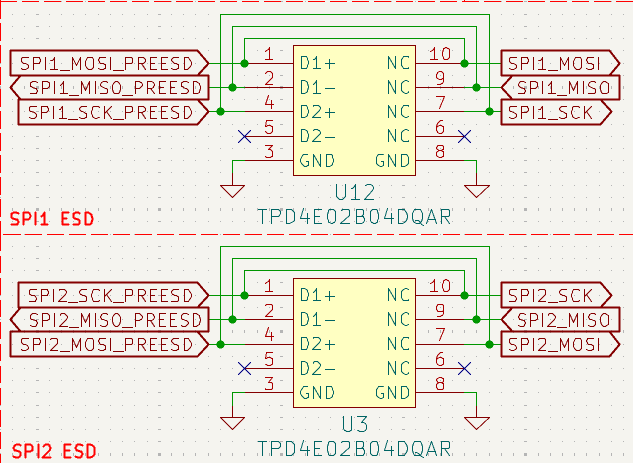
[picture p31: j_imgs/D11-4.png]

These are the connections for the near-MCU ESD chip covering the encoders' and motor drivers' SPI lines.
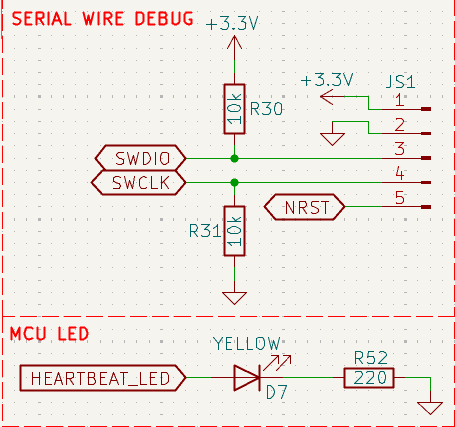
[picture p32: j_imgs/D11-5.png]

These are the serial wire debug and heartbeat LED connections. For serial wire debug I'll be using an ST-Link, so there are five pins for that.
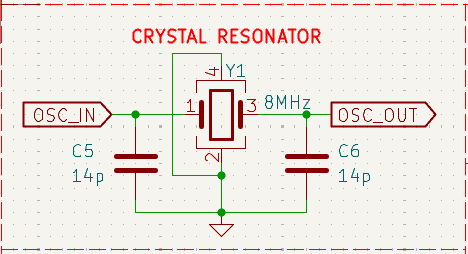
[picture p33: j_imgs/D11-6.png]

This is the crystal resonator, also mentioned in devlog 2. I've just used global labels here to keep it neater.

**Total time spent: 2 hours**

# 2026-06-27: Stage 1 — Custom STM32F446-Based Motor Controller (Dev Board) - DEVLOG12 - MCU SETUP


I've finished wiring up the MCU as well, with all the labels established and connected, and I did some cleaning up and arranging the components, overall making the schematics neat. A couple of series resistors are used on lines where current limiting is required. VCAP has a 4.7µF capacitor tied to it, as per ST's guidance. I've transferred this schematic layout from STM32CubeMX.

This is the STM32CubeMX pin layout. The CubeMX report is available in [\Stage1 - STM\CubeMX](https://github.com/atharvach2007/arsenal/blob/main/Stage1%20-%20STM/CubeMX), along with the IOC file in the same folder. All of the schematics are available in [\Stage1 - STM\voxboard](https://github.com/atharvach2007/arsenal/tree/main/Stage1%20-%20STM/voxboard).
With this, I've completed the schematics for the 6-DOF ARSENAL arm. Next, I'll move on to routing the PCB.
Entire Schematic

**Total time spent: 1 hour**

# 2026-07-20: Stage 1 — Custom STM32F446-Based Motor Controller (Dev Board) - DEVLOG13 - ROUTING #1 SETUP 

With the schematics completed, I moved on to routing. Before getting into it properly, I took a short break to work on some other projects. Once I got back to it, the first step was creating a rough layout, since this board has a large number of connectors and connection types, along with two entirely separate power rails. To manage this, I split the layout into two sections: one containing all the 3.3V components and the other containing all the 24V components. I went through three main layout iterations, with my primary concern throughout being the power circuitry. Since I estimated a maximum current draw of around 13A, I wanted to make sure the routing could comfortably handle that load without issues.

I started by placing the core MCU components: the decoupling capacitors, the crystal oscillator, and the rest of the essential MCU circuitry, including the ESD protection ICs, which I had planned to place close to the MCU, as well as the resistors for the SPI CS lines. From there, I grouped the remaining sections of the board by function, bringing the I2C connectors together, the SPI encoder connectors together, and the CAN bus connectors together along with their supporting circuitry.

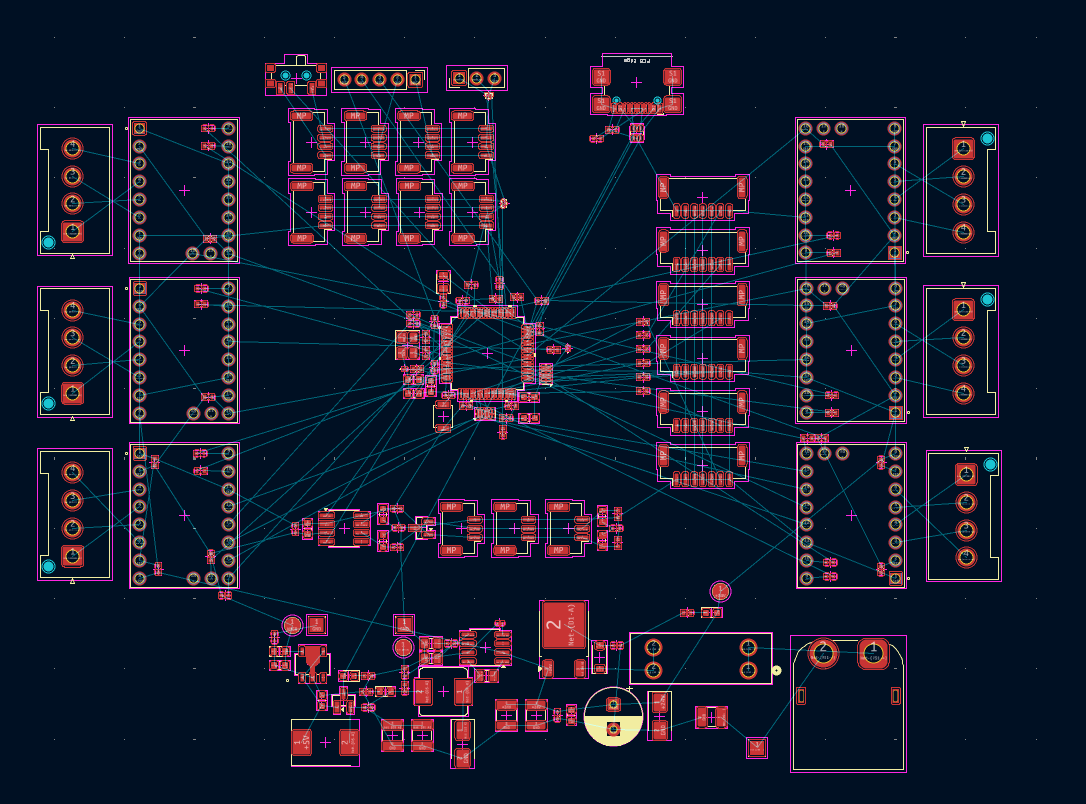
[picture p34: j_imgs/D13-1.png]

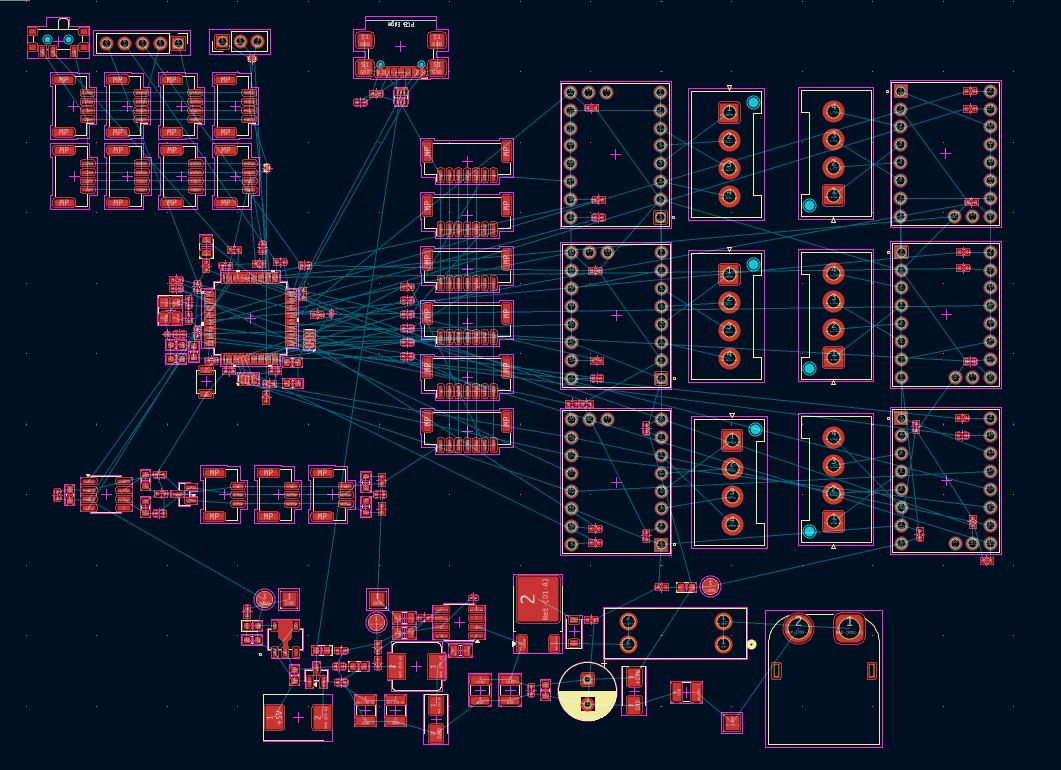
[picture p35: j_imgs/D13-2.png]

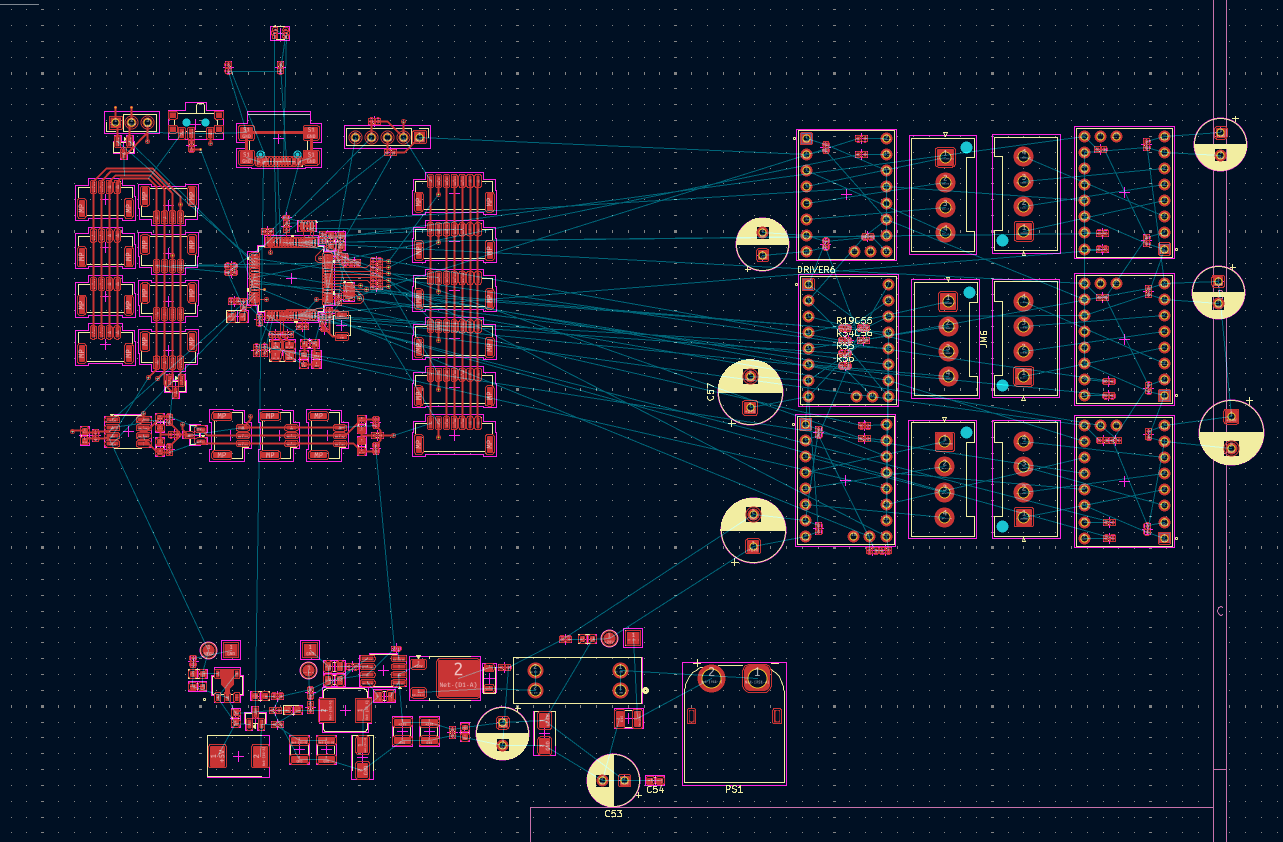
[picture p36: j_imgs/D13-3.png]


In layout 3, you'll notice six new electrolytic capacitors. I added these afterward to help suppress stepper motor noise that could otherwise leak into the logic rails, which would cause problems downstream. For now, I'm planning to move forward with this third layout as my base. The power circuitry has also been arranged temporarily at this stage, and I'll continue refining it as the design progresses.

An important note, my board has a 4 layer stackup of SIG - GND - POW (3.3V) - SIG.

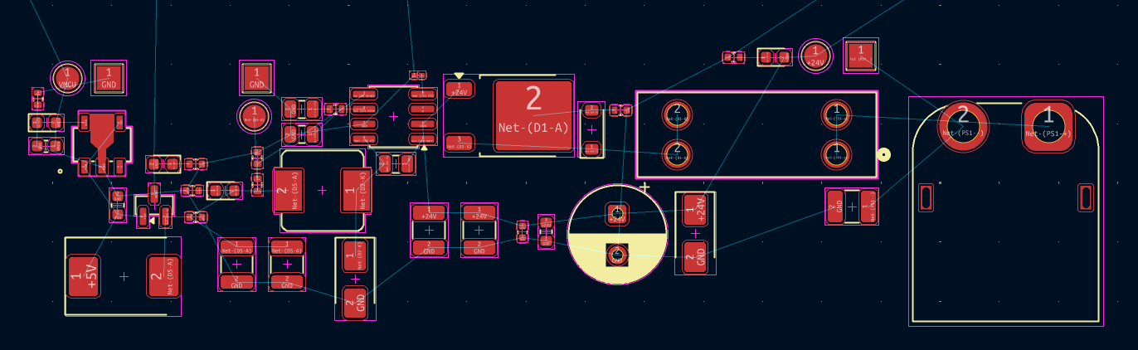
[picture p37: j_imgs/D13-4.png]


With the basic layout in place, the next step is routing the MCU and its direct connections first.

**Total time spent: 3 hours**

# 2026-07-21: Stage 1 — Custom STM32F446-Based Motor Controller (Dev Board) - DEVLOG14 - ROUTING #2 SIMPLE LOGIC CONNECTIONS 

After the rough placement, I routed the core MCU components: the power pin decoupling capacitors, the analog 3.3V connections, the crystal oscillator, series resistors on some of the I2C and SPI CS lines, the ESD protection ICs for the SPI lines, and the heartbeat LED. This layout isn't final and will likely change as the design progresses. One thing I'm considering is moving the NRST button, boot button, and heartbeat LED closer to the board boundary, both for easier access and to reduce crowding around the MCU. I'm using vias mainly for the 3.3V and GND connections, and reserving the back copper layer for the motor driver circuitry further out on the board.

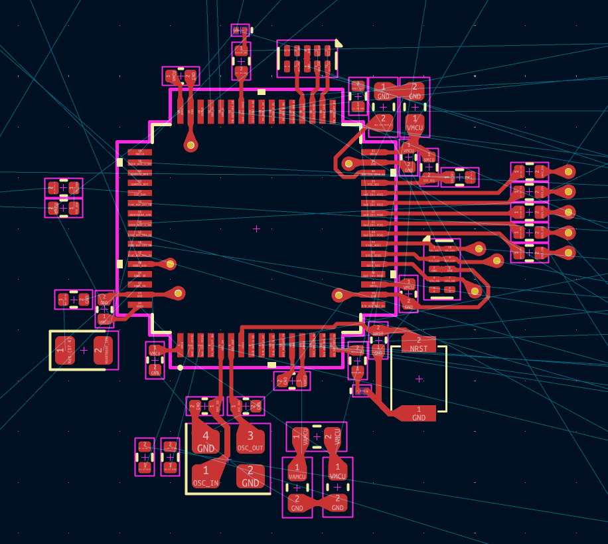
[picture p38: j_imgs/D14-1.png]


Next was the USB-C connector, which involved differential pairs and needed a bit more care. I kept the traces as short and straight as possible and placed the ESD chip right over the main differential pair. The remaining connections around it were fairly straightforward.

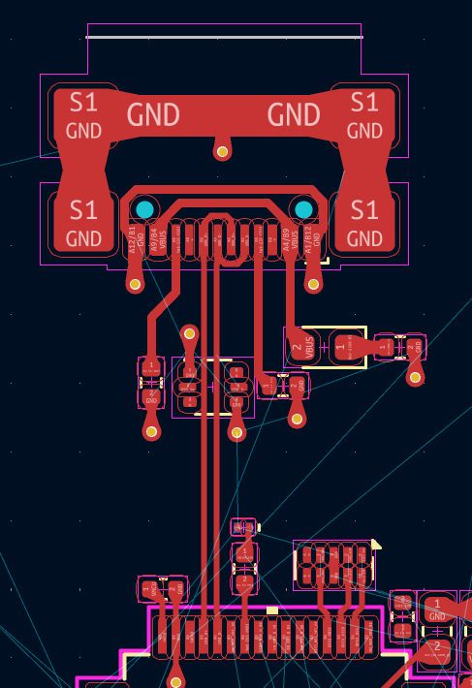
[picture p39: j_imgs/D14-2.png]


After that came the simpler connector routing for the encoder SPI and I2C ports.

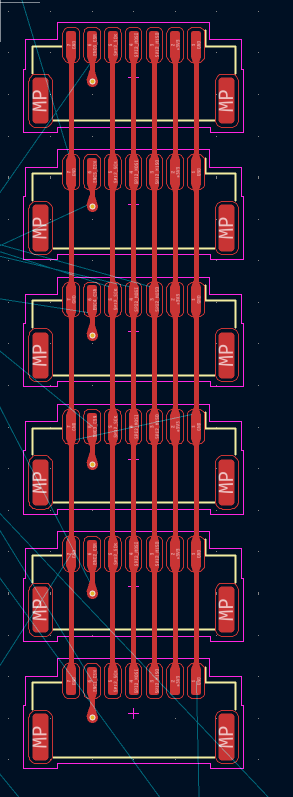
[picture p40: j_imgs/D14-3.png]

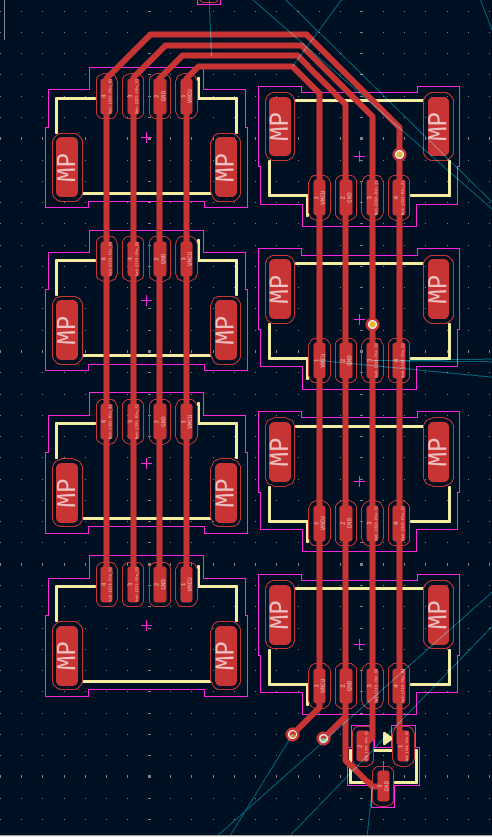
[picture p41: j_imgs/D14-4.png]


The next major piece was the CAN bus, which is mainly there to serve as a connector for the end effector. Routing itself was fairly easy, though the main challenge was fitting everything into a fairly compact area.

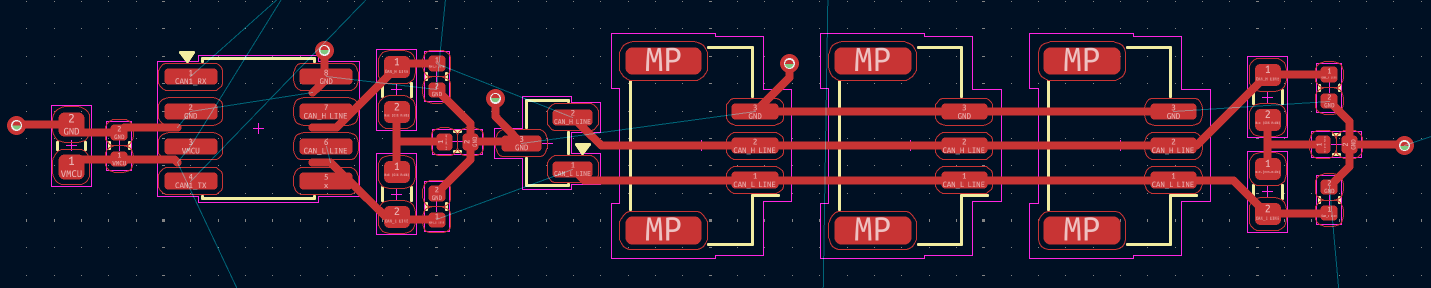
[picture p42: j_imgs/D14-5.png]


With the basic routing done, I'll move on to the power lines next.

**Total time spent: 4 hours**

# 2026-07-23: Stage 1 — Custom STM32F446-Based Motor Controller (Dev Board) - DEVLOG15 - ROUTING #3 POWER CONNECTIONS - 1 

My main concern at this stage was figuring out how to carry such high current across the board while keeping the motor current properly isolated from the logic current. I started by laying down thick traces capable of handling the 13A requirement I'd estimated earlier.

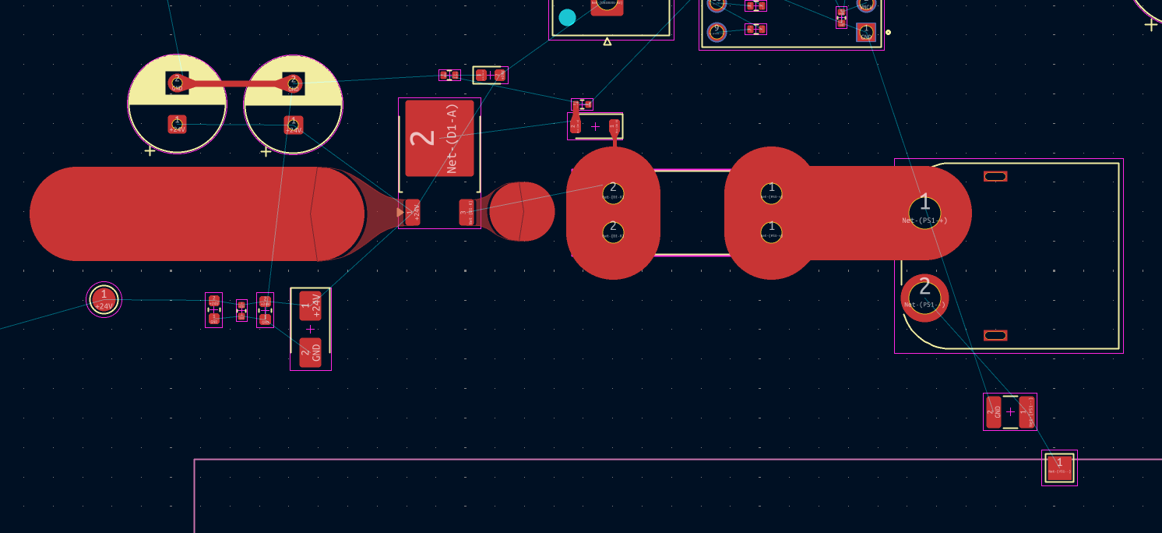
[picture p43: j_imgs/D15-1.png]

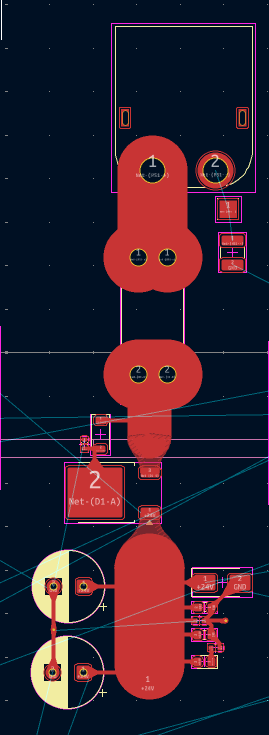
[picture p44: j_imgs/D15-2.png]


This does look a bit messy, but I couldn't really come up with a cleaner approach given the constraints. Next, I moved on to wiring up the smaller components for the buck converter and the LDO, trying to keep the whole configuration as compact as possible. This ended up being the most time consuming part of the whole process. I spent hours re-iterating on the layout, shrinking it down bit by bit each time I found a slightly better arrangement.

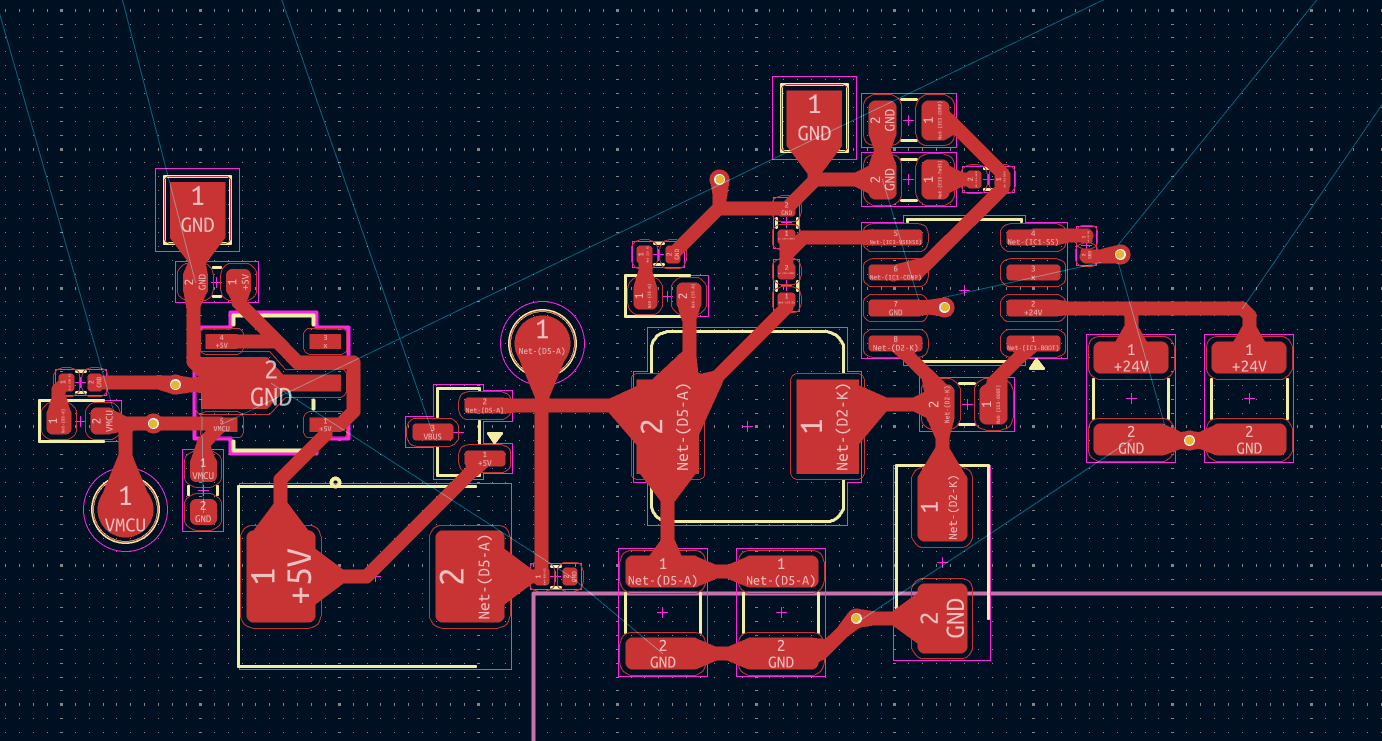
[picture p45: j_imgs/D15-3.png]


Along the way, I also revised the motor driver layout. I decided to run the entire power rail between the rows of drivers, so that the 24V side stays isolated on one side of the board while the 3.3V connections can travel across to the other side using the third power layer.

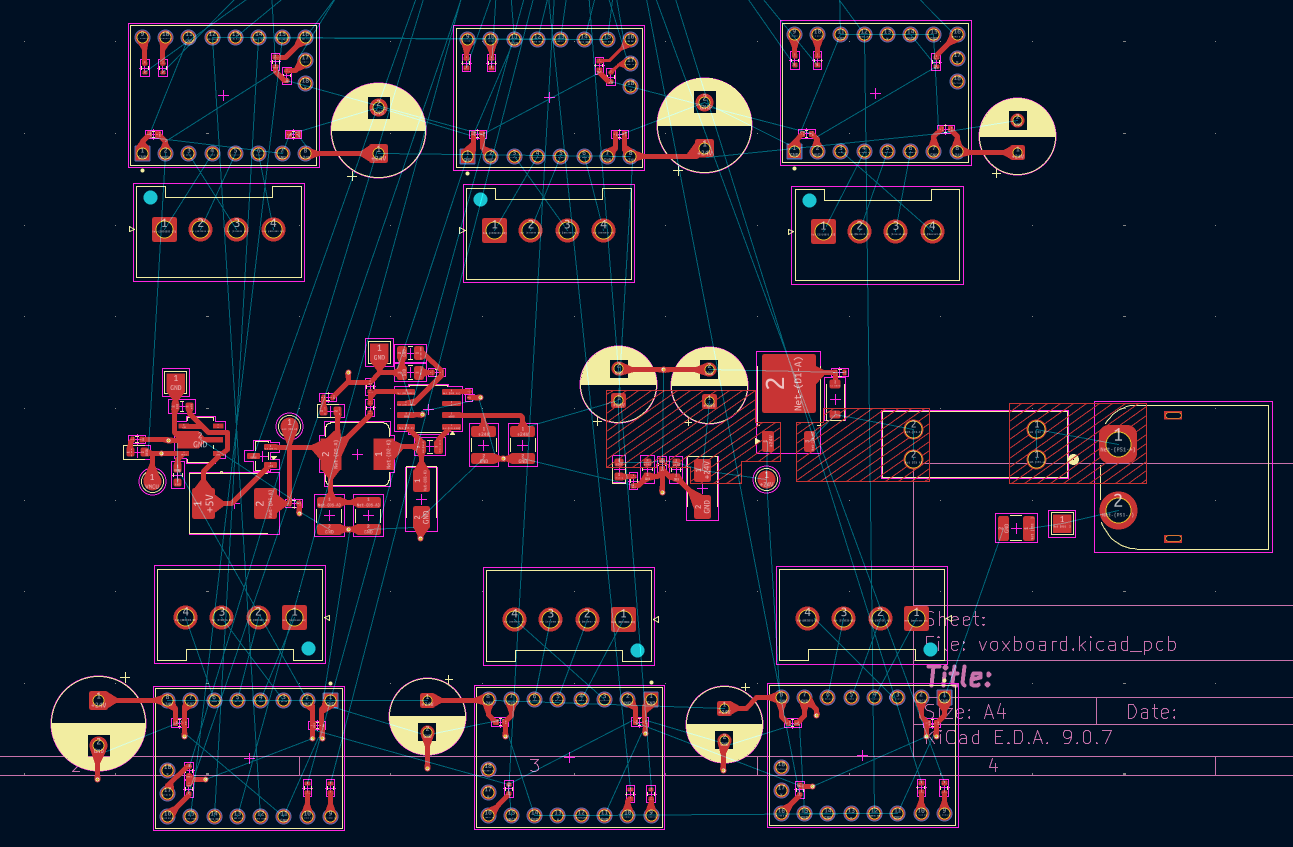
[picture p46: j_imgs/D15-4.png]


The bigger challenge after that was figuring out how to extend traces out to the 24V inputs of each driver from the central thick trace. After a fair bit of trial and error, I landed on a spider-like branching structure that seemed to work well. Part of the difficulty here was that this isn't the only set of traces converging near the drivers, so I had to leave enough room to account for the other connections that would eventually need to pass through the same area.

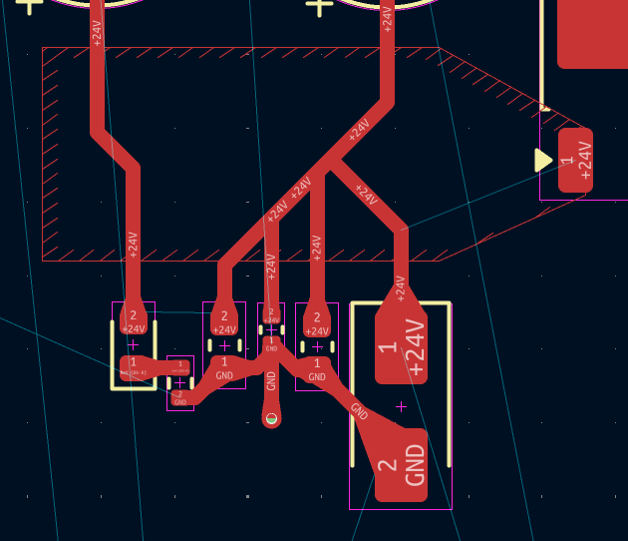
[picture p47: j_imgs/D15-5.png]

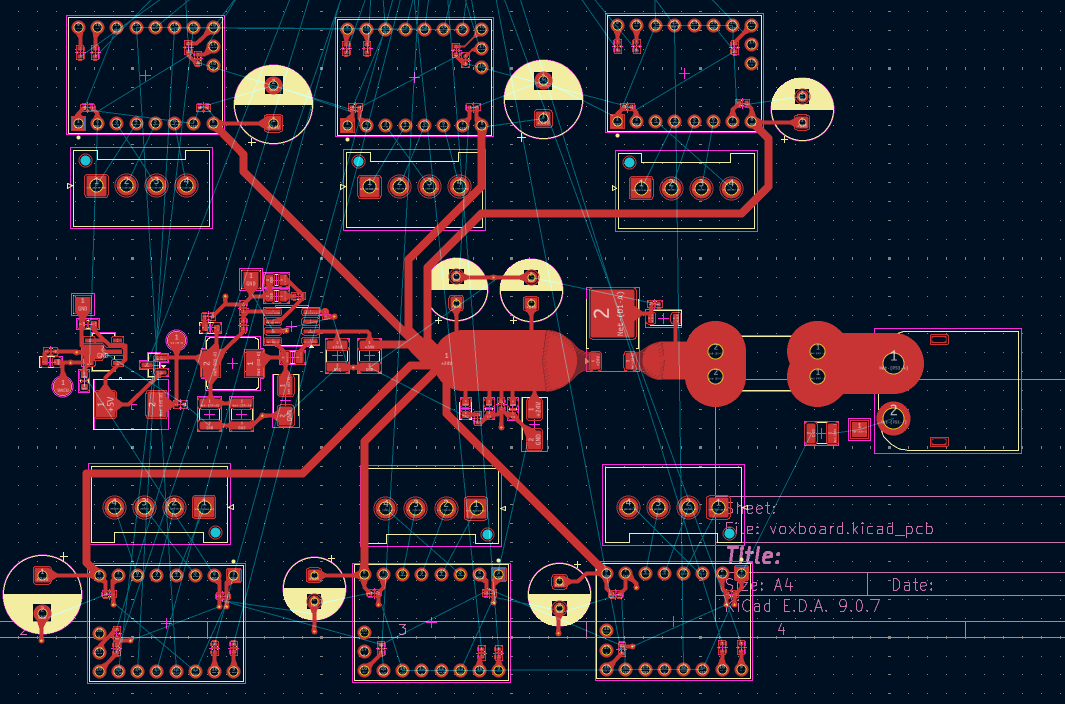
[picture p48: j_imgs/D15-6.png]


With the power routing mostly done for now, I'll probably move on to the remaining connections next, but I might revisit this tomorrow.

**Total time spent: 5 hours**

# 2026-07-24: Stage 1 — Custom STM32F446-Based Motor Controller (Dev Board) - DEVLOG16 - ROUTING #4 POWER CONNECTIONS - 2 

After sharing this setup with a few friends on Slack and getting laughed at over the spider structure I made, they suggested I switch to using fill zones instead. Since a fill zone would handle the current distribution far more cleanly than a tangle of individually routed traces. So my plan going forward is to build a fill zone shaped like a tree across the top layer, since 1oz copper will be used for the top layer, and leave the third layer reserved for the 3.3V connections.

With that done, I'm quite satisfied with how it turned out, though I still think there's room to make the overall design more compact. So I will be spending some more time on that front as well, mostly just shifting components around and tightening up the spacing wherever possible. I won't be documenting every small shift here, but I'll include the final result in my closing devlog for this board.


**Total time spent: 2 hours**

# 2026-07-27 to 2026-08-24: Stage 1 — Custom STM32F446-Based Motor Controller (Dev Board) - DEVLOG17 - ROUTING #5 OVERALL CONNECTIONS - 1

I stopped working on this project consistently once school started, so I only managed to squeeze in small bits of progress whenever I found some spare time. Because of that, this stretch isn't documented nearly as well as my other journals. So instead of trying to create a set of day-by-day journals, I'll be combining all of these smaller bits and posting 4 long journals covering everything I worked on over this month-long tenure. This was also my first time building a devboard this complex, so things took a lot longer than they should have, but I learned quite a lot in the process.

So, once the main power rail was done, which basically involved wiring the input into a small filtering network with back-EMF protection, this now reasonably clean 24V input was fed into the motors. The same input was also tapped off into a buck converter, producing a 5V/3A output, which then feeds into an LDO to finally produce a stable 3.3V/1A rail for the logic side.


With that settled, the main routing left was connecting the MCU to the rest of the board. To start off, I routed the connections to the nearby I2C and CAN connectors, which were pretty straightforward and didn't need much thought. Next up was the CSN lines going to the encoder SPI connectors, which had to pass through series resistors placed close to the MCU to keep the signal integrity reasonable.

Speaking of placement near the MCU, let me elaborate a bit on my ESD protection plan, since it's something I put a fair bit of thought into. Basically, I have two different placement strategies depending on the type of connection. Connectors that go off-board to the outside world, things like USB-C, CAN, RPi UART, and I2C, get their ESD protection placed right at the connector itself. That's because that's exactly where a static discharge or a cable-insertion transient would actually enter the board, and stopping it right there means it never gets the chance to couple onto anything else further downstream. On the other hand, buses that stay entirely internal to the board, like SPI1 going to the encoders, SPI2 going to the TMC5160 drivers, and the TMC2209 UART buses, don't really have an external entry point in the same sense, so their ESD protection sits near the MCU instead, guarding the chip's pins directly on a shared bus trunk that feeds several onboard devices at once.

**Total time spent: 7 hours**

# 2026-07-27 to 2026-08-24: Stage 1 — Custom STM32F446-Based Motor Controller (Dev Board) - DEVLOG18 - ROUTING #6 OVERALL CONNECTIONS - 2

Now onto the actual routing grind. Once these peripherals were in place, the board very quickly started getting cluttered, a lot more than I expected. I kept running into situations where I simply couldn't route something because there was always some other trace or component blocking the path. So after a round of very tedious rearrangements, things slowly started coming together, though it definitely wasn't smooth.

As I started routing the connections to the motor drivers, specifically the DIR and STEP pins, it became difficult getting traces across to the other side of the board. This is where I made a fairly big mistake early on: I ended up routing the logic traces before the signal traces, which meant that by the time I got to the signal traces, they had become a nightmare to manage since all the easy paths were already taken.


Another problem that came up was that my initial component placement had the encoder connectors sitting right between the MCU and the drivers, which wasn't ideal. So I had to remove the existing connections entirely and rework the placement. Since I wanted to keep the board as compact as possible, this meant making a few changes, the main one being folding the CAN bus layout so that the transceiver IC now sits vertically above the connectors instead of alongside them. The new layout ended up with USB on the left, along with the serial wire and RPi UART, encoders on top, and I2C on the side. This arrangement conveniently leaves the bottom layer almost completely free of traces, since the I2C connectors only need the top layer here, with the CAN bus sitting at the bottom of the board.


From there, I started routing all the different logic connections to the drivers, leaving the signal connections for last since I knew those would need more careful handling. A lot of problems came up here, mainly around figuring out how to route everything to where it actually needed to go. A recurring issue was pins conflicting with each other, like two adjacent pins that both needed to travel toward each other, creating a barrier between them. These small problems ended up eating a surprising amount of time individually.
But after wrestling with this for a long time, most of the main routing was finally done. I then moved on to the signal lines, which, after a lot of back and forth and liberal use of vias to hop between layers, were also eventually finished.


**Total time spent: 7 hours**

# 2026-07-27 to 2026-08-24: Stage 1 — Custom STM32F446-Based Motor Controller (Dev Board) - DEVLOG19 - ROUTING #6 OVERALL CONNECTIONS - 3

At this point, a new problem arrived: a handful of pins on the MCU had ended up boxed in, meaning I couldn't route them out on either layer since they were completely surrounded by other traces on all sides. To fix this, I had to REROUTE for the 3rd time.

Once this round of rerouting was done, I posted my design in a friend's Slack channel to get some feedback, and basically got met with horror. Well atleast I got some advice. The first was that I should be placing ground vias around any vias carrying high-speed signals, a method known as via stitching. The idea is that it gives the return current a short, direct path to follow alongside the signal instead of forcing it to detour around the board, which keeps inductance low and helps avoid EMI issues down the line. The second, related concept was via fencing, which is essentially the same idea scaled up: a full ring of ground vias placed around a wider area for broader shielding, rather than just single vias next to individual signals. So I went through and added around 2 ground vias per signal via, and things were looking good after that.


I then moved on to creating the pours for my 3.3V layer, basically laying down a bunch of layer fills exactly where I wanted the pours to sit, and at this point I thought I was done. I created the ground fill as well, set up the board boundaries, and everything seemed finished and tidy.

That is, until someone on Slack pointed out that my vias had "1-2" or "1-3" written on them instead of going all the way through. Basically, I had assumed early on that vias connecting to the ground plane or the 3.3V plane didn't need to go all the way through the board, thinking this would save some routing area on the bottom layer. So, without fully realizing it, I had ended up using microvias for essentially everything. Every single via on the board turned out to be a microvia.

I tried using the "edit via properties" option to fix this in one go, but that didn't work the way I expected, and all of my vias remained stubbornly micro. Somehow I had ended up with microvias set to custom dimensions I had defined myself, so when I ran edit via properties, every single one of them got reset to the default netclass dimensions for microvias instead, which only made the mess worse. In the end, I had to delete each via individually and manually add normal through-hole vias in their place. While I was at it, I checked JLCPCB's manufacturing specs and found 0.4/0.3mm to be the smallest "free" via size they could reliably produce, so I standardized every via on the board to that size going forward.



**Total time spent: 7 hours**

# 2026-07-27 to 2026-08-24: Stage 1 — Custom STM32F446-Based Motor Controller (Dev Board) - DEVLOG20 - ROUTING #7 OVERALL CONNECTIONS - 4

The via change, of course, gave rise to a fresh set of problems. The updated via sizes and clearances made my 3.3V pour discontinuous, since all vias were now punching all the way through the board instead of stopping partway. I had to go back and reconfigure the placement of both the vias and the pours to restore continuity. On top of that, a lot of these newly resized vias now sat directly over traces on the bottom layer, so a majority of those traces had to be REROUTED, for the 4th time. This time, I made sure to double-check clearances, via sizes, and track sizes across the entire board, and I di believe I was done.


Then someone then brought up return paths, which tied directly back into the via stitching discussion from earlier. They pointed out that signals like UART and SPI shouldn't be routed directly over the power pours I had created on layer 3, since doing so disrupts the return current path. My routing had a good number of signal traces crossing right over that pour. So I had to reroute these signal traces yet again, this time by bringing them up to the top layer and shuffling other components and traces around to make room. By this point, a substantial amount of routing had already been completed, and to free up the necessary space, I ended up having to delete most of it, again.

This time, though, it really was the final rerouting. After spending a few more days tidying up and polishing the board, I redrew the board boundary, merged all the separate fill zones belonging to the same nets, and also discovered that the terminals on my XT60 connector symbol were reversed, which I fixed. I added a few extra decoupling capacitors near the negative terminal, removed the ferrite bead I'd initially placed, and made a handful of other small cleanup changes, and with that, I was done. Period.


From there, I moved on to adding all the missing 3D models in KiCad. I couldn't track down an existing 3D model for the inductor, so I ended up modeling one myself in Fusion 360. The motor drivers didn't have models available either, so I made those from scratch as well, complete with connector slots to match the real footprints. I also swapped out the JST connectors I had originally used for the motors in favor of JST-XH ones instead, for a more secure and standard connection.

With all of that wrapped up, I added some silkscreen details: a short note explaining what the board is, my personal hallmark and logo, and a couple of other fun little touches. I then tidied up the schematic sheet, filled in a few remaining details, and with that, VoxBoard V1 was officially done.
Here are the Results.




This was the final compressed layout of the power circuitry.





It's beautiful.

**Total time spent: 7 hours**

# 2026-10-01: Stage 1 — Custom STM32F446-Based Motor Controller (Dev Board) - DEVLOG21 - BOM

So I exported the BOM from KiCad through the fabrication tool and then sat down to find all the JLC part numbers for these parts. While doing that, I had to change some of the footprints, since I'm not sure why exactly I chose those footprints when they didn't have parts available in that size or form. There were some major changes that involved rearranging some parts on the power rail, but it wasn't a big deal and got resolved easily.




So, after these small changes, uploading the BOM to JLC and finalizing my parts cart was done. The BOM is present in [\Stage1 - STM](https://github.com/shadedvox/arsenal/tree/main/Stage1%20-%20STM). The parts total, as of October 2026, comes out to $263.61 for 2 PCBAs. This is only the parts total; the PCBA and PCB manufacturing charges still need to be calculated.




**Total time spent: 2 hours**

# 2026-10-03: Stage 1 — Custom STM32F446-Based Motor Controller (Dev Board) - DEVLOG22 - GND POURS, VIA STITCHING

This journal entry is mainly to commemorate my stupidity: I spent two hours placing via stitching patterns manually, completely unaware that plugins exist to do it automatically. That's all—I manually placed via stitches all over the board after creating GND pours on both signal layers.




This is the final showcase of Voxboard V1.









**Total time spent: 2 hours**

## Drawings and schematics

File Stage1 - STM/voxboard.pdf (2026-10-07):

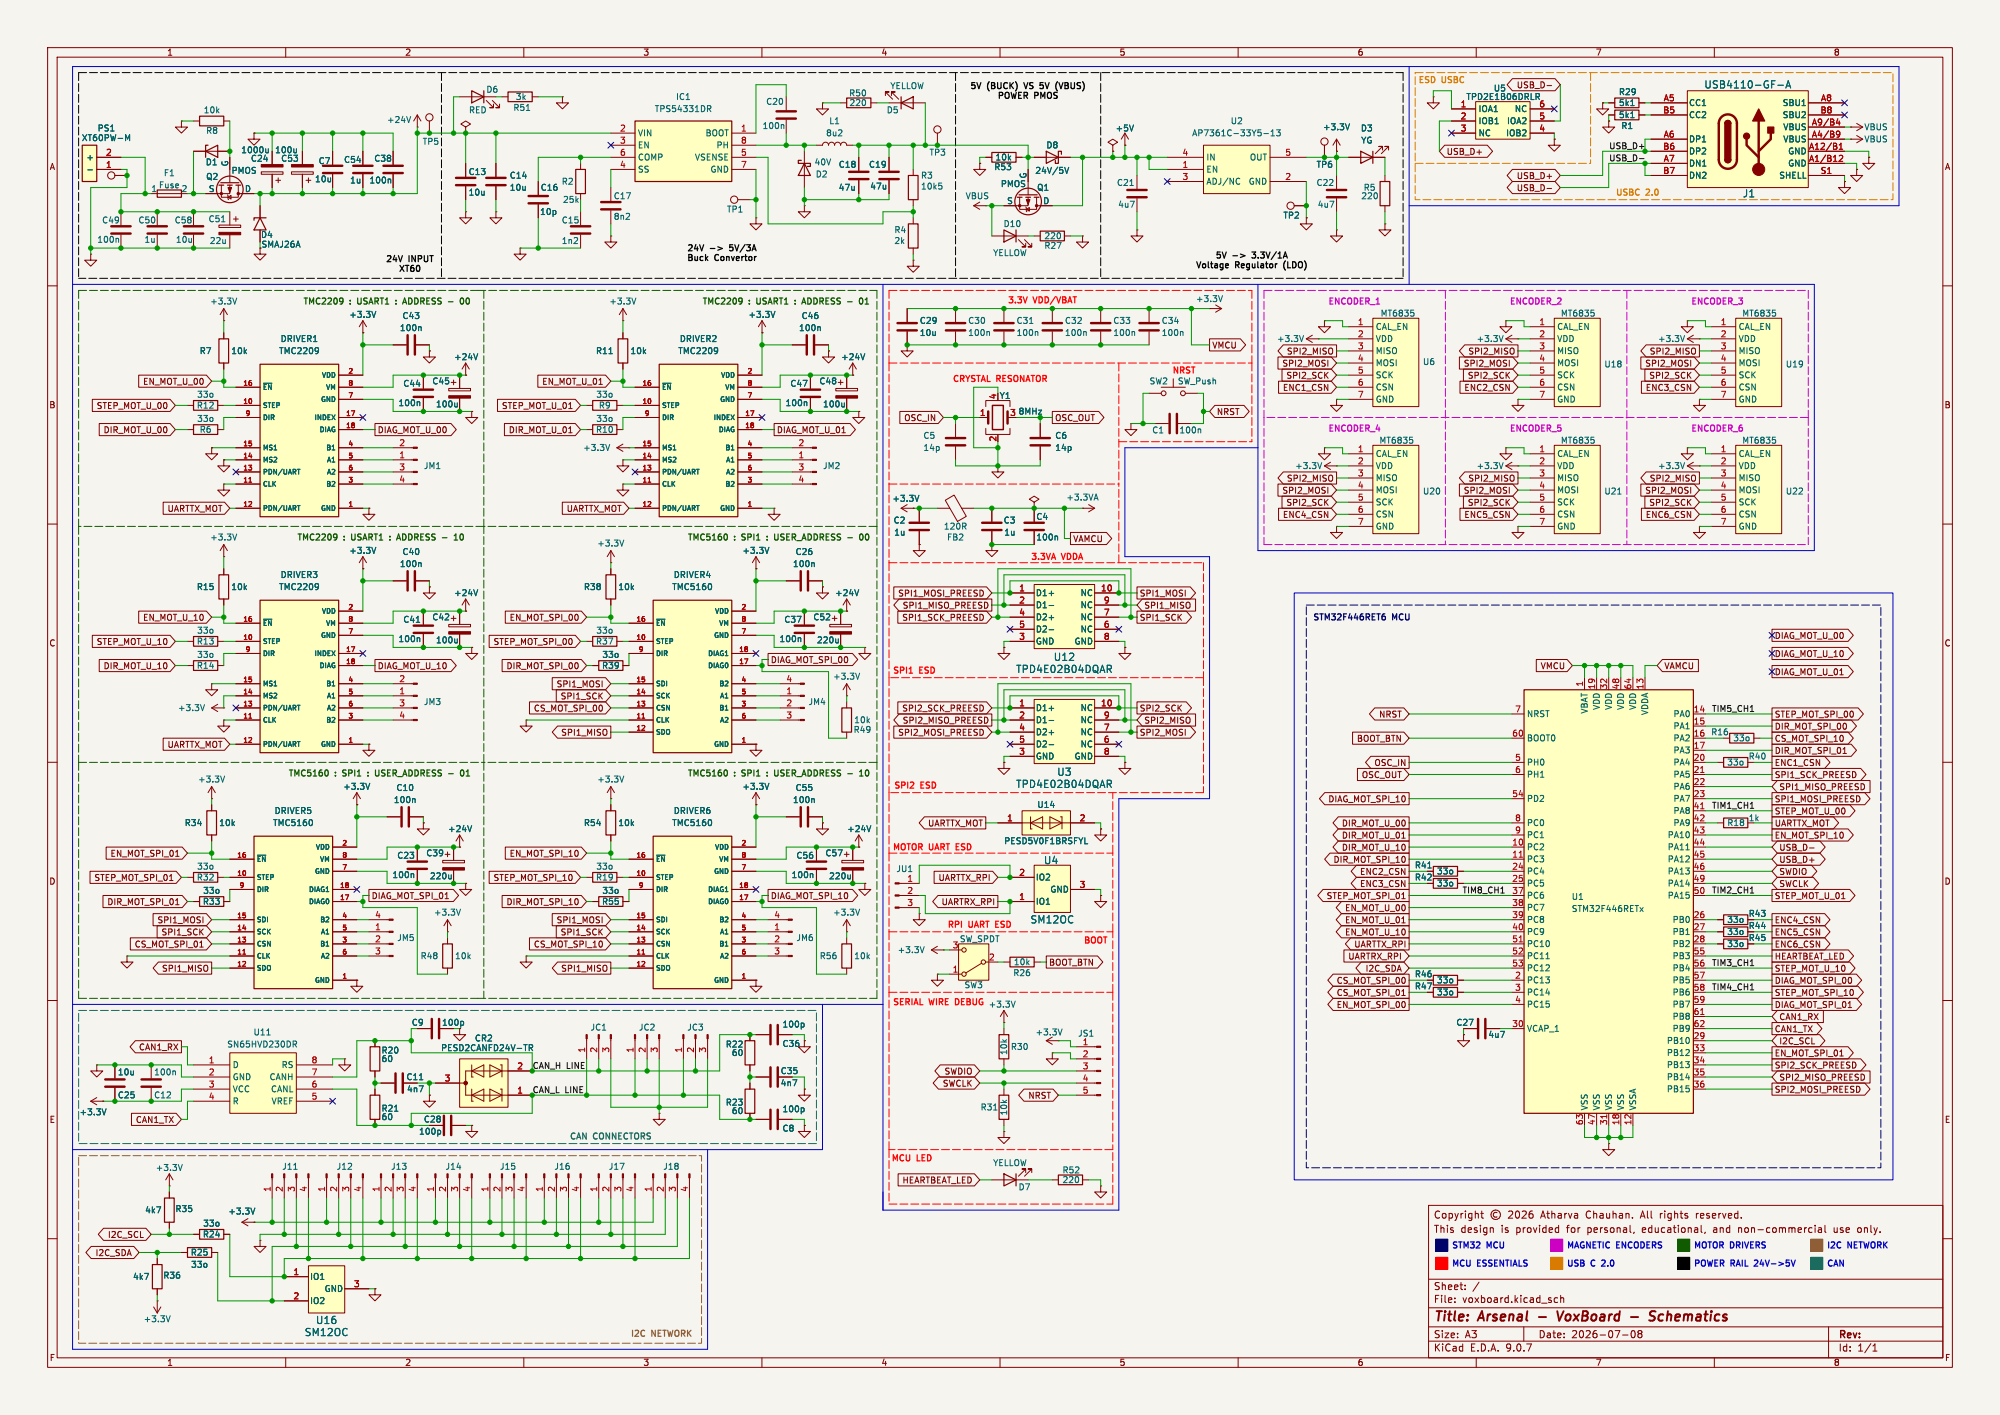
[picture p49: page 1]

Voltage Regulator (LDO) 5V (BUCK) VS 5V (VBUS) POWER PMOS

1 VSS 63 VDD 19 VSS 47 VDD 32 VSS 31 VDD 48 VSS 18 VDD 64 VSSA 12 VDDA 13 PA0

RPI UART ESD MOTOR UART ESD

Id: 1/1 Title: Arsenal - VoxBoard - Schematics

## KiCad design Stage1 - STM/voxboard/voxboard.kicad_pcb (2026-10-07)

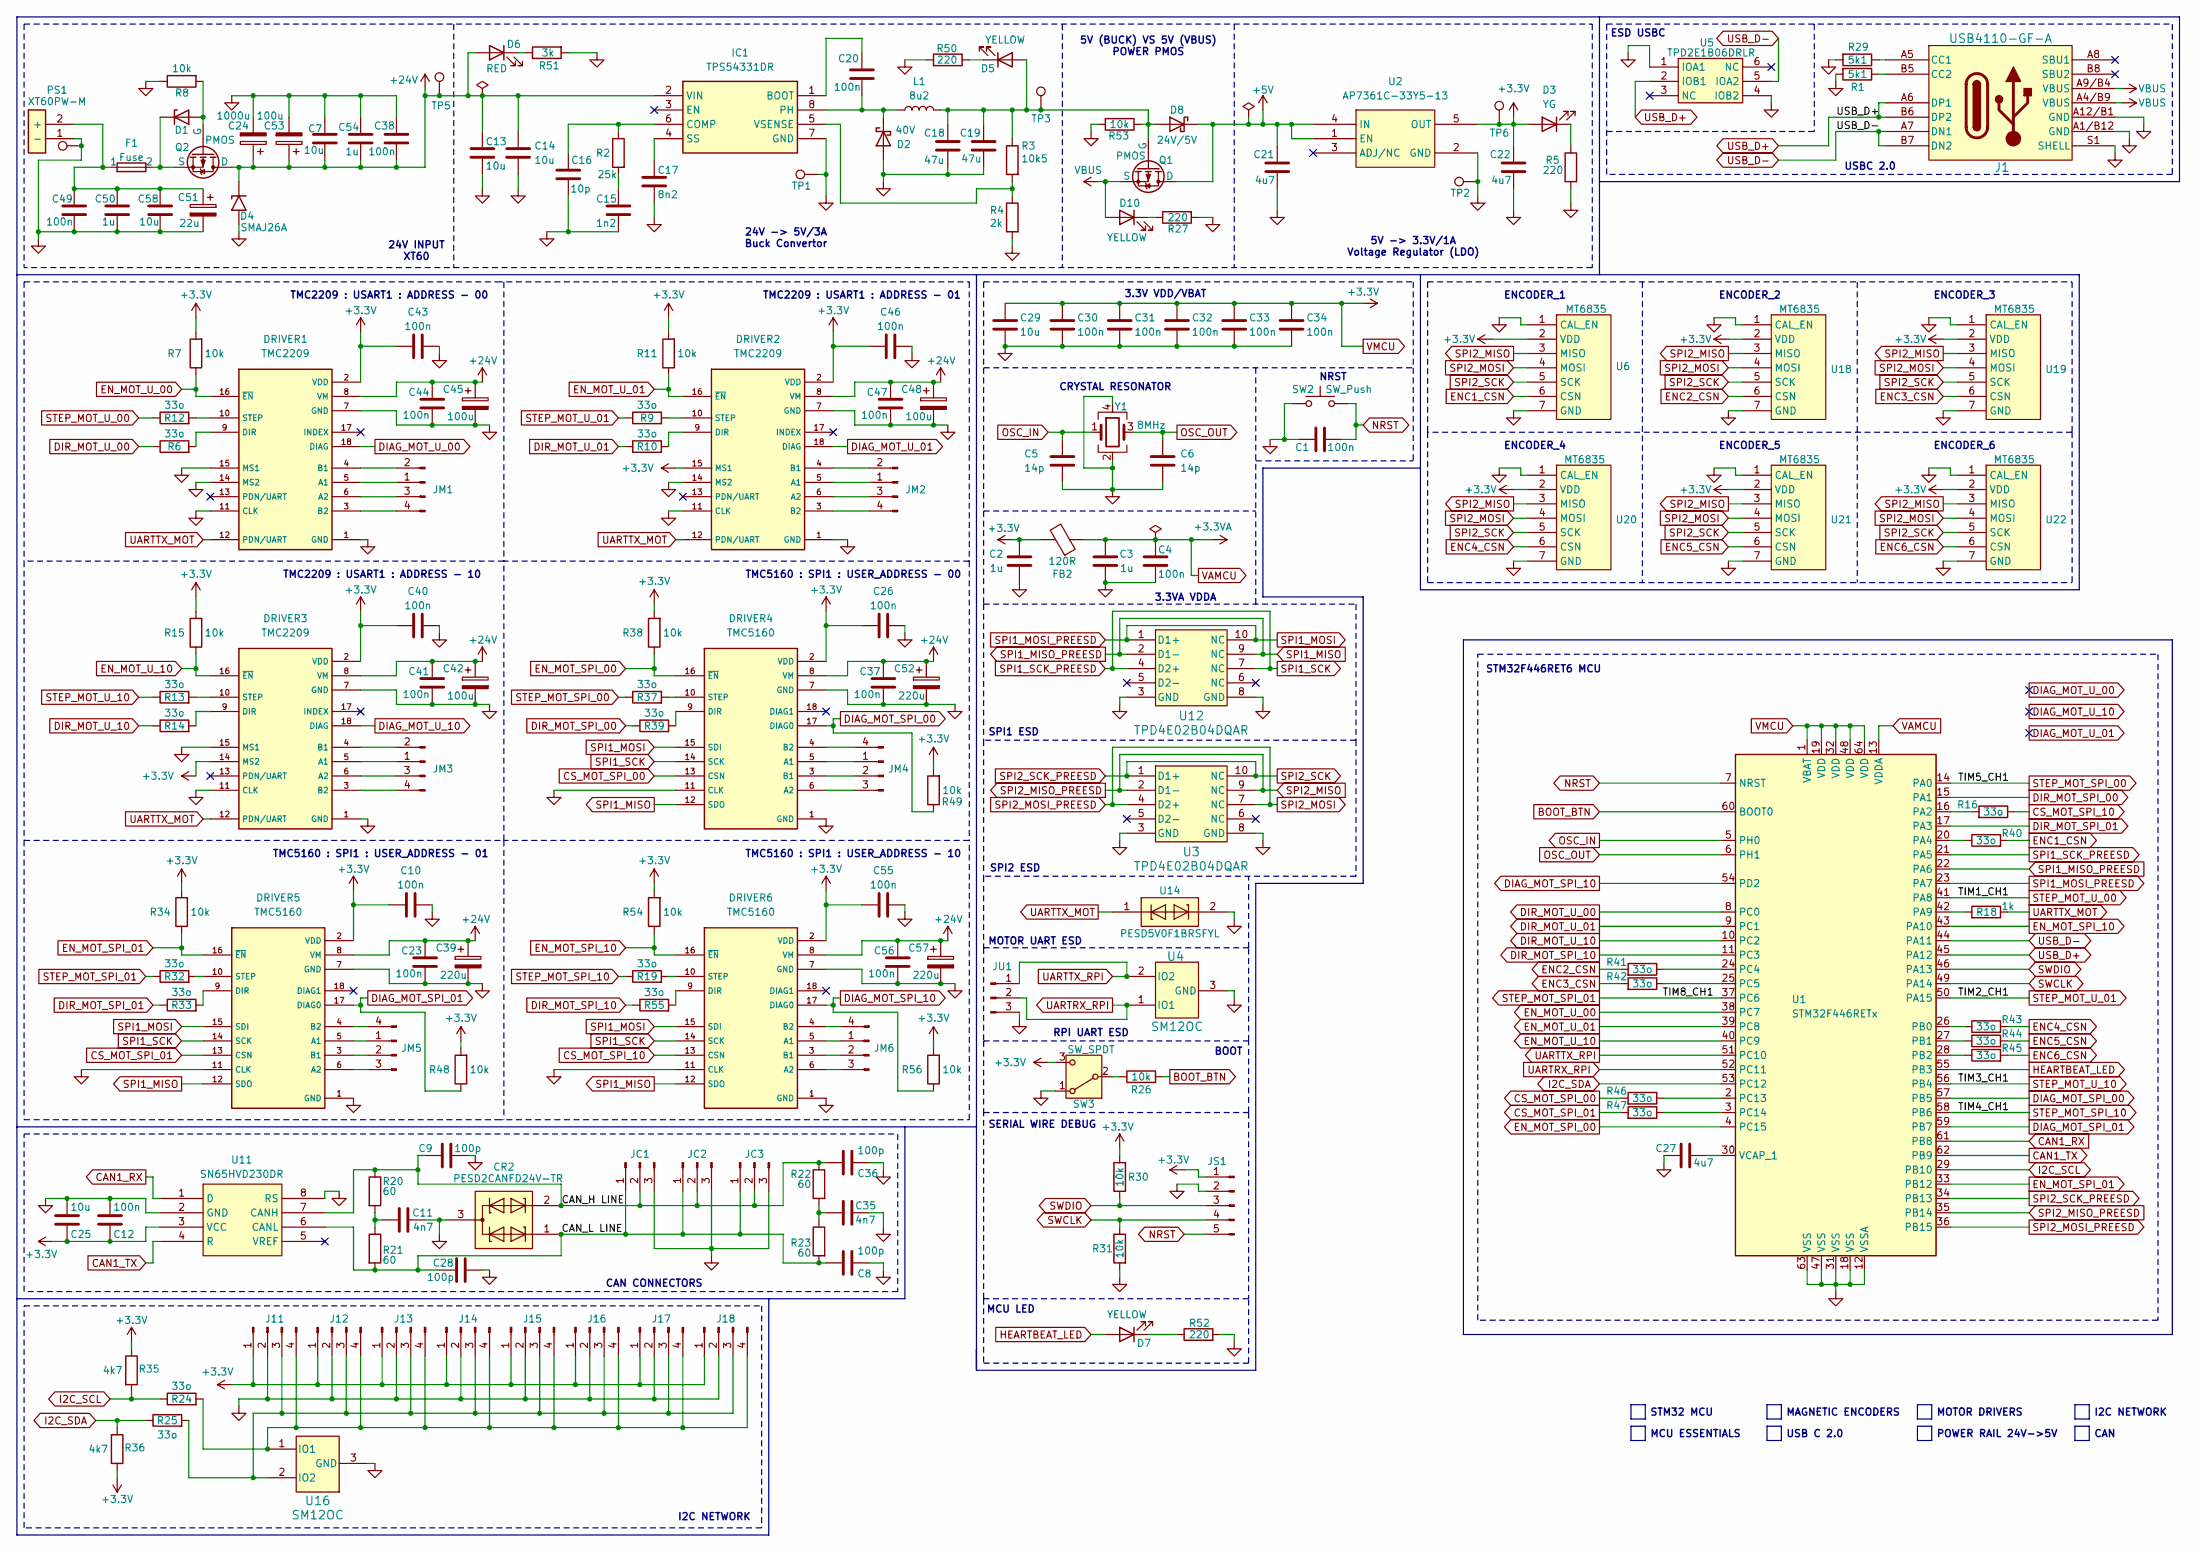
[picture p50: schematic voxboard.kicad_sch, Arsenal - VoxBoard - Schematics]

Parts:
C1, C4, C10, C12, C23, C26, C30, C31, C32, C33, C34, C37, C38, C40, C41, C43, C44, C46, C47, C49, C55, C56: 100n; C_0402_1005Metric
C2, C3, C50, C54: 1u; C_0603_1608Metric
C5, C6: 14p; C_0402_1005Metric
C7, C25, C29, C58: 10u; C_0805_2012Metric
C8, C9, C28, C36: 100p; C_0402_1005Metric
C11, C35: 4n7; C_0402_1005Metric
C13, C14: 10u; C_1210_3225Metric
C15: 1n2; C_0805_2012Metric
C16: 10p; C_0805_2012Metric
C17: 8n2; C_0201_0603Metric
C18, C19: 47u; C_1210_3225Metric
C20: 100n; C_0805_2012Metric
C21, C22, C27: 4u7; C_0603_1608Metric
C24: 1000u; CP_Radial_D12.5mm_P5.00mm
C39, C52, C57: 220u; CP_Radial_D10.0mm_P5.00mm
C42, C45, C48: 100u; CP_Radial_D8.0mm_P3.50mm
C51: 22u; CP_Radial_D5.0mm_P2.00mm
C53: 100u; CP_Radial_D6.3mm_P2.50mm
CR2: PESD2CANFD24V-TR; SOT-23
D1: D_Zener; D_SOD-123
D2: 40V; D_SMC
D3: YG; LED_0603_1608Metric
D4: SMAJ26A; D_SMA
D5, D10: YELLOW; LED_0603_1608Metric
D6: RED; LED_0603_1608Metric
D7: YELLOW; LED_0805_2012Metric
D8: 24V/5V; SOT-23
DRIVER1, DRIVER2, DRIVER3: TMC2209; MODULE_TMC2209_5160
DRIVER4, DRIVER5, DRIVER6: TMC5160; MODULE_TMC2209_5160
F1: Fuse; CONN_3557-2_KEY
FB2: 120R; L_0603_1608Metric
IC1: TPS54331DR; SOIC-8_3.9x4.9mm_P1.27mm
J1: USB4110-GF-A; USB_C_Receptacle_GCT_USB4110
J11, J12, J13, J14, J15, J16, J17, J18: Conn_01x04_Pin; JST_GH_BM04B-GHS-TBT_1x04-1MP_P1.25mm_Vertical
JC1, JC2, JC3: Conn_01x03_Pin; JST_GH_BM03B-GHS-TBT_1x03-1MP_P1.25mm_Vertical
JM1, JM2, JM3, JM4, JM5, JM6: Conn_01x04_Pin; JST_XA_B04B-XASK-1_1x04_P2.50mm_Vertical
JS1: Conn_01x05_Pin; PinHeader_1x05_P2.54mm_Vertical
JU1: Conn_01x03_Pin; PinHeader_1x03_P2.54mm_Vertical
L1: 8u2; L_KOHERELEC_MDA7050_7.3x6.6mm
PS1: XT60PW-M; AMASS_XT60PW-M_1x02_P7.20mm_Horizontal
Q1: PMOS; SOT-23
Q2: PMOS; TO-252-2
R1, R29: 5k1; R_0402_1005Metric
R2: 25k; R_0603_1608Metric
R3: 10k5; R_0402_1005Metric
R4: 2k; R_0402_1005Metric
R5, R27, R50, R52: 220; R_0402_1005Metric
R6, R9, R10, R12, R13, R14, R16, R19, R24, R25, R32, R33, R37, R39, R40, R41, R42, R43, R44, R45, R46, R47, R55: 33o; R_0402_1005Metric
R7, R8, R11, R15, R26, R30, R31, R34, R38, R48, R49, R53, R54, R56: 10k; R_0402_1005Metric
R18: 1k; R_0402_1005Metric
R20, R21, R22, R23: 60; R_0603_1608Metric
R35, R36: 4k7; R_0402_1005Metric
R51: 3k; R_0402_1005Metric
SW2: SW_Push; SW_PUSH_B3U-1000PM
SW3: SW_SPDT; SW_SPDT_PCM12
TP1, TP2, TP4: TestPoint; TestPoint_Pad_2.0x2.0mm
TP3, TP5, TP6: TestPoint; TestPoint_Pad_D2.0mm
U1: STM32F446RETx; LQFP64-10x10mm
U2: AP7361C-33Y5-13; AP7361C-33Y5-13_SOT89-5_DIO
U3, U12: TPD4E02B04DQAR; USON-10_2.5x1.0mm_P0.5mm
U4, U16: SM12OC; SOT-23
U5: TPD2E1B06DRLR; SOT-666
U6, U18, U19, U20, U21, U22: MT6835; JST_GH_BM07B-GHS-TBT_1x07-1MP_P1.25mm_Vertical
U11: SN65HVD230DR; SOIC-8_3.9x4.9mm_P1.27mm
U14: PESD5V0F1BRSFYL; Nexperia_DSN0603-2_0.6x0.3mm_P0.4mm
Y1: 8MHz; Crystal_SMD_3225-4Pin_3.2x2.5mm

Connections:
+5V: C21.1, D8.1 (K), Q1.1 (D), U2.1 (EN), U2.4 (IN)
+24V: C7.2, C13.1, C14.1, C23.1, C24.1, C37.1, C38.2, C39.1, C41.1, C42.1, C44.1, C45.1, C47.1, C48.1, C52.1, C53.1, C54.2, C56.1, C57.1, D4.1 (A1), D6.2 (A), DRIVER1.8 (VM), DRIVER2.8 (VM), DRIVER3.8 (VM), DRIVER4.8 (VM), DRIVER5.8 (VM), DRIVER6.8 (VM), IC1.2 (VIN), Q2.1 (D), TP5.1
/CAN_H LINE: C9.1, C36.1, CR2.2, JC1.2, JC2.2, JC3.2, R20.1, R22.1, U11.7 (CANH)
/CAN_L LINE: C8.1, C28.1, CR2.1, JC1.1, JC2.1, JC3.1, R21.2, R23.2, U11.6 (CANL)
BOOT_BTN: R26.2, U1.60 (BOOT0)
CAN1_RX: U1.61 (PB8), U11.1 (D)
CAN1_TX: U1.62 (PB9), U11.4 (R)
CS_MOT_SPI_00: DRIVER4.13 (CSN), R46.2
CS_MOT_SPI_01: DRIVER5.13 (CSN), R47.2
CS_MOT_SPI_10: DRIVER6.13 (CSN), R16.1
DIAG_MOT_SPI_00: DRIVER4.17 (DIAG0), R49.1, U1.57 (PB5)
DIAG_MOT_SPI_01: DRIVER5.17 (DIAG0), R48.1, U1.59 (PB7)
DIAG_MOT_SPI_10: DRIVER6.17 (DIAG0), R56.1, U1.54 (PD2)
DIAG_MOT_U_00: DRIVER1.18 (DIAG)
DIAG_MOT_U_01: DRIVER2.18 (DIAG)
DIAG_MOT_U_10: DRIVER3.18 (DIAG)
DIR_MOT_SPI_00: R39.1, U1.15 (PA1)
DIR_MOT_SPI_01: R33.1, U1.17 (PA3)
DIR_MOT_SPI_10: R55.1, U1.11 (PC3)
DIR_MOT_U_00: R6.1, U1.8 (PC0)
DIR_MOT_U_01: R10.1, U1.9 (PC1)
DIR_MOT_U_10: R14.1, U1.10 (PC2)
ENC1_CSN: R40.2, U6.6 (CSN)
ENC2_CSN: R41.2, U18.6 (CSN)
ENC3_CSN: R42.2, U19.6 (CSN)
ENC4_CSN: R43.2, U20.6 (CSN)
ENC5_CSN: R44.2, U21.6 (CSN)
ENC6_CSN: R45.2, U22.6 (CSN)
EN_MOT_SPI_00: DRIVER4.16 (~EN), R38.1, U1.4 (PC15)
EN_MOT_SPI_01: DRIVER5.16 (~EN), R34.1, U1.33 (PB12)
EN_MOT_SPI_10: DRIVER6.16 (~EN), R54.1, U1.43 (PA10)
EN_MOT_U_00: DRIVER1.16 (~EN), R7.1, U1.38 (PC7)
EN_MOT_U_01: DRIVER2.16 (~EN), R11.1, U1.39 (PC8)
EN_MOT_U_10: DRIVER3.16 (~EN), R15.1, U1.40 (PC9)
GND: C1.1, C2.2, C3.2, C4.2, C5.2, C6.2, C7.1, C8.2, C9.2, C10.2, C11.2, C12.2, C13.2, C14.2, C15.2, C16.2, C17.2, C18.2, C19.2, C21.2, C22.2, C23.2, C24.2, C25.2, C26.2, C27.1, C28.2, C29.2, C30.2, C31.2, C32.2, C33.2, C34.2, C35.2, C36.2, C37.2, C38.1, C39.2, C40.2, C41.2, C42.2, C43.2, C44.2, C45.2, C46.2, C47.2, C48.2, C49.2, C50.2, C51.2, C52.2, C53.2, C54.1, C55.2, C56.2, C57.2, C58.2, CR2.3, D2.2 (A), D4.2 (A2), DRIVER1.1 (GND), DRIVER1.7 (GND), DRIVER1.11 (CLK), DRIVER1.14 (MS2), DRIVER1.15 (MS1), DRIVER2.1 (GND), DRIVER2.7 (GND), DRIVER2.11 (CLK), DRIVER2.14 (MS2), DRIVER3.1 (GND), DRIVER3.7 (GND), DRIVER3.11 (CLK), DRIVER3.15 (MS1), DRIVER4.1 (GND), DRIVER4.7 (GND), DRIVER4.11 (CLK), DRIVER5.1 (GND), DRIVER5.7 (GND), DRIVER5.11 (CLK), DRIVER6.1 (GND), DRIVER6.7 (GND), DRIVER6.11 (CLK), IC1.7 (GND), J1.A1/B12 (GND), J1.A12/B1 (GND), J1.S1 (SHELL), J11.2, J12.2, J13.2, J14.2, J15.2, J16.2, J17.2, J18.2, JC1.3, JC2.3, JC3.3, JS1.2, JU1.3, PS1.1 (-), R1.2, R4.2, R5.2, R8.1, R27.2, R29.2, R31.2, R50.2, R51.2, R52.2, R53.2, SW2.1, SW3.1 (A), TP1.1, TP2.1, TP4.1, U1.12 (VSSA), U1.18 (VSS), U1.31 (VSS), U1.47 (VSS), U1.63 (VSS), U2.2 (GND), U3.3 (GND), U3.8 (GND), U4.3 (GND), U5.1 (IOA1), U5.4 (IOB2), U6.1 (CAL_EN), U6.7 (GND), U11.2 (GND), U11.8 (RS), U12.3 (GND), U12.8 (GND), U14.2, U16.3 (GND), U18.1 (CAL_EN), U18.7 (GND), U19.1 (CAL_EN), U19.7 (GND), U20.1 (CAL_EN), U20.7 (GND), U21.1 (CAL_EN), U21.7 (GND), U22.1 (CAL_EN), U22.7 (GND), Y1.2 (G), Y1.4 (G)
HEARTBEAT_LED: D7.2 (A), U1.55 (PB3)
I2C_SCL: R24.1, R35.2, U1.29 (PB10)
I2C_SDA: R25.1, R36.1, U1.53 (PC12)
NRST: C1.2, JS1.5, SW2.2, U1.7 (NRST)
unnamed: C11.1, R20.2, R21.1
unnamed: C15.1, R2.2
unnamed: C35.1, R22.2, R23.1
unnamed: D1.2 (A), Q2.2 (G), R8.2
unnamed: D1.1 (K), F1.2, Q2.3 (S)
unnamed: C20.2, D2.1 (K), IC1.8 (PH), L1.1
unnamed: D3.1 (K), R5.1
unnamed: C18.1, C19.1, D5.2 (A), D8.2 (A), L1.2, Q1.2 (G), R3.1, R53.1, TP3.1
unnamed: D5.1 (K), R50.1
unnamed: D6.1 (K), R51.1
unnamed: D7.1 (K), R52.1
unnamed: D10.1 (K), R27.1
unnamed: DRIVER1.5 (A1), JM1.1
unnamed: DRIVER1.6 (A2), JM1.3
unnamed: DRIVER1.4 (B1), JM1.2
unnamed: DRIVER1.3 (B2), JM1.4
unnamed: DRIVER1.9 (DIR), R6.2
unnamed: DRIVER1.10 (STEP), R12.2
unnamed: DRIVER2.5 (A1), JM2.1
unnamed: DRIVER2.6 (A2), JM2.3
unnamed: DRIVER2.4 (B1), JM2.2
unnamed: DRIVER2.3 (B2), JM2.4
unnamed: DRIVER2.9 (DIR), R10.2
unnamed: DRIVER2.10 (STEP), R9.2
unnamed: DRIVER3.5 (A1), JM3.1
unnamed: DRIVER3.6 (A2), JM3.3
unnamed: DRIVER3.4 (B1), JM3.2
unnamed: DRIVER3.3 (B2), JM3.4
unnamed: DRIVER3.9 (DIR), R14.2
unnamed: DRIVER3.10 (STEP), R13.2
unnamed: DRIVER4.5 (A1), JM4.1
unnamed: DRIVER4.6 (A2), JM4.3
unnamed: DRIVER4.3 (B1), JM4.2
unnamed: DRIVER4.4 (B2), JM4.4
unnamed: DRIVER4.9 (DIR), R39.2
unnamed: DRIVER4.10 (STEP), R37.2
unnamed: DRIVER5.5 (A1), JM5.1
unnamed: DRIVER5.6 (A2), JM5.3
unnamed: DRIVER5.3 (B1), JM5.2
unnamed: DRIVER5.4 (B2), JM5.4
unnamed: DRIVER5.9 (DIR), R33.2
unnamed: DRIVER5.10 (STEP), R32.2
unnamed: DRIVER6.5 (A1), JM6.1
unnamed: DRIVER6.6 (A2), JM6.3
unnamed: DRIVER6.3 (B1), JM6.2
unnamed: DRIVER6.4 (B2), JM6.4
unnamed: DRIVER6.9 (DIR), R55.2
unnamed: DRIVER6.10 (STEP), R19.2
unnamed: C20.1, IC1.1 (BOOT)
unnamed: C16.1, IC1.6 (COMP), R2.1
unnamed: C17.1, IC1.4 (SS)
unnamed: IC1.5 (VSENSE), R3.2, R4.1
unnamed: J1.A5 (CC1), R29.1
unnamed: J1.B5 (CC2), R1.1
unnamed: J11.3, J12.3, J13.3, J14.3, J15.3, J16.3, J17.3, J18.3, R25.2, U16.2 (IO2)
unnamed: J11.4, J12.4, J13.4, J14.4, J15.4, J16.4, J17.4, J18.4, R24.2, U16.1 (IO1)
unnamed: C49.1, C50.1, C51.1, C58.1, F1.1, PS1.2 (+)
unnamed: R26.1, SW3.2 (B)
unnamed: R16.2, U1.16 (PA2)
unnamed: R40.1, U1.20 (PA4)
unnamed: R18.2, U1.42 (PA9)
unnamed: R43.1, U1.26 (PB0)
unnamed: R44.1, U1.27 (PB1)
unnamed: R45.1, U1.28 (PB2)
unnamed: R41.1, U1.24 (PC4)
unnamed: R42.1, U1.25 (PC5)
unnamed: R46.1, U1.2 (PC13)
unnamed: R47.1, U1.3 (PC14)
unnamed: C27.2, U1.30 (VCAP_1)
OSC_IN: C5.1, U1.5 (PH0), Y1.1
OSC_OUT: C6.1, U1.6 (PH1), Y1.3
SPI1_MISO: DRIVER4.12 (SDO), DRIVER5.12 (SDO), DRIVER6.12 (SDO), U1.22 (PA6), U12.2 (D1-), U12.9 (NC)
SPI1_MOSI: DRIVER4.15 (SDI), DRIVER5.15 (SDI), DRIVER6.15 (SDI), U1.23 (PA7), U12.1 (D1+), U12.10 (NC)
SPI1_SCK: DRIVER4.14 (SCK), DRIVER5.14 (SCK), DRIVER6.14 (SCK), U1.21 (PA5), U12.4 (D2+), U12.7 (NC)
SPI2_MISO: U1.35 (PB14), U3.2 (D1-), U3.9 (NC), U6.3 (MISO), U18.3 (MISO), U19.3 (MISO), U20.3 (MISO), U21.3 (MISO), U22.3 (MISO)
SPI2_MOSI: U1.36 (PB15), U3.4 (D2+), U3.7 (NC), U6.4 (MOSI), U18.4 (MOSI), U19.4 (MOSI), U20.4 (MOSI), U21.4 (MOSI), U22.4 (MOSI)
SPI2_SCK: U1.34 (PB13), U3.1 (D1+), U3.10 (NC), U6.5 (SCK), U18.5 (SCK), U19.5 (SCK), U20.5 (SCK), U21.5 (SCK), U22.5 (SCK)
STEP_MOT_SPI_00: R37.1, U1.14 (PA0)
STEP_MOT_SPI_01: R32.1, U1.37 (PC6)
STEP_MOT_SPI_10: R19.1, U1.58 (PB6)
STEP_MOT_U_00: R12.1, U1.41 (PA8)
STEP_MOT_U_01: R9.1, U1.50 (PA15)
STEP_MOT_U_10: R13.1, U1.56 (PB4)
SWCLK: JS1.4, R31.1, U1.49 (PA14)
SWDIO: JS1.3, R30.1, U1.46 (PA13)
UARTRX_RPI: JU1.2, U1.52 (PC11), U4.1 (IO1)
UARTTX_MOT: DRIVER1.12 (PDN/UART), DRIVER2.12 (PDN/UART), DRIVER3.12 (PDN/UART), R18.1, U14.1
UARTTX_RPI: JU1.1, U1.51 (PC10), U4.2 (IO2)
USB_D+: J1.A6 (DP1), J1.B6 (DP2), U1.45 (PA12), U5.2 (IOB1)
USB_D-: J1.A7 (DN1), J1.B7 (DN2), U1.44 (PA11), U5.5 (IOA2)
VAMCU: C3.1, C4.1, FB2.1, U1.13 (VDDA)
VBUS: D10.2 (A), J1.A4/B9 (VBUS), J1.A9/B4 (VBUS), Q1.3 (S)
VMCU: C2.1, C10.1, C12.1, C22.1, C25.1, C26.1, C29.1, C30.1, C31.1, C32.1, C33.1, C34.1, C40.1, C43.1, C46.1, C55.1, D3.2 (A), DRIVER1.2 (VDD), DRIVER2.2 (VDD), DRIVER2.15 (MS1), DRIVER3.2 (VDD), DRIVER3.14 (MS2), DRIVER4.2 (VDD), DRIVER5.2 (VDD), DRIVER6.2 (VDD), FB2.2, J11.1, J12.1, J13.1, J14.1, J15.1, J16.1, J17.1, J18.1, JS1.1, R7.2, R11.2, R15.2, R30.2, R34.2, R35.1, R36.2, R38.2, R48.2, R49.2, R54.2, R56.2, SW3.3 (C), TP6.1, U1.1 (VBAT), U1.19 (VDD), U1.32 (VDD), U1.48 (VDD), U1.64 (VDD), U2.5 (OUT), U6.2 (VDD), U11.3 (VCC), U18.2 (VDD), U19.2 (VDD), U20.2 (VDD), U21.2 (VDD), U22.2 (VDD)

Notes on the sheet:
ESD USBC
TMC5160 : SPI1 : USER_ADDRESS - 10
STM32 MCU
NRST
TMC5160 : SPI1 : USER_ADDRESS - 01
ENCODER_4
MOTOR UART ESD
TMC2209 : USART1 : ADDRESS - 10
TMC2209 : USART1 : ADDRESS - 01
ENCODER_6
MOTOR DRIVERS
BOOT
MAGNETIC ENCODERS
RPI UART ESD
3.3V VDD/VBAT
CAN
TMC5160 : SPI1 : USER_ADDRESS - 00
ENCODER_5
CAN CONNECTORS
SPI1 ESD
USBC 2.0
I2C NETWORK
MCU ESSENTIALS
3.3VA VDDA
ENCODER_2
24V -> 5V/3A Buck Convertor
SPI2 ESD
ENCODER_3
USB C 2.0
MCU LED
POWER RAIL 24V->5V
CRYSTAL RESONATOR
SERIAL WIRE DEBUG
STM32F446RET6 MCU
5V -> 3.3V/1A Voltage Regulator (LDO)
TMC2209 : USART1 : ADDRESS - 00
24V INPUT XT60
ENCODER_1
5V (BUCK) VS 5V (VBUS) POWER PMOS

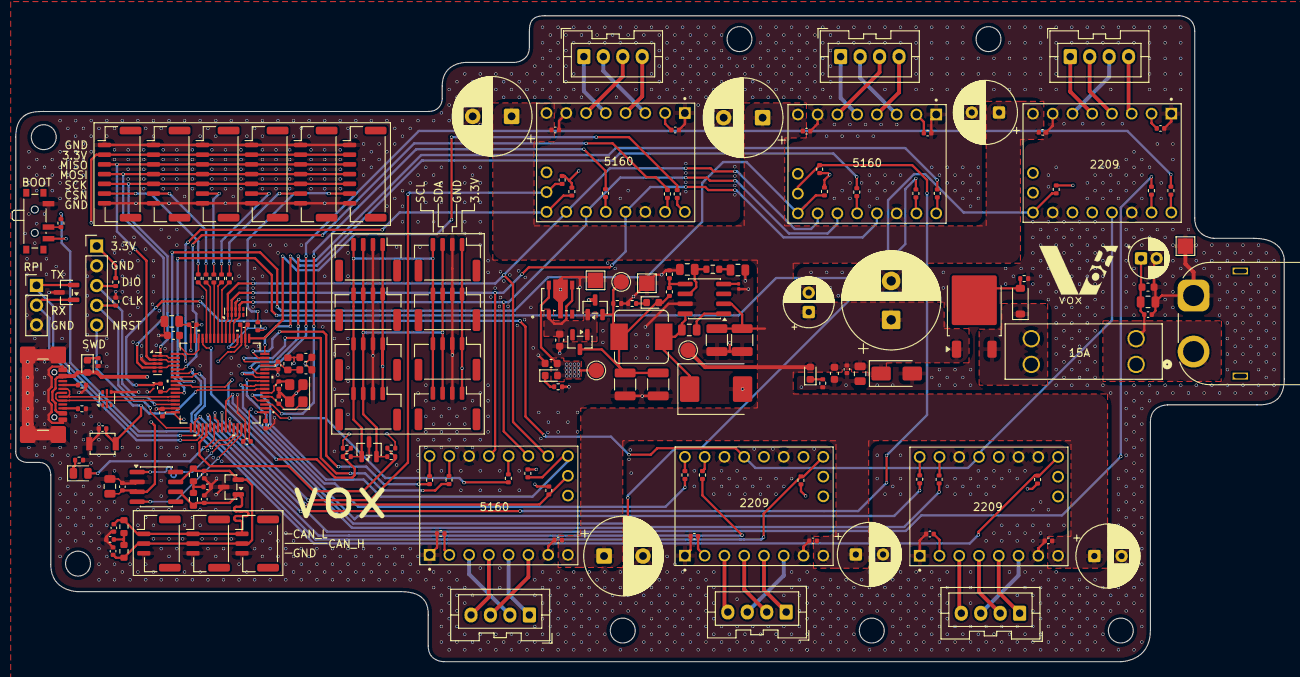
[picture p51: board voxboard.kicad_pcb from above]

Board: 4 copper layers, 163.0 x 83.0 mm, 179 parts (0 on the bottom side), 129 nets.

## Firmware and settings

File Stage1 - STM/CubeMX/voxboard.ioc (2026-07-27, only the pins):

Mcu.UserName=STM32F446RETx
PA0-WKUP.Signal=S_TIM5_CH1
PA1.Signal=GPIO_Output
PA10.Signal=GPIO_Output
PA11.Signal=USB_OTG_FS_DM
PA12.Signal=USB_OTG_FS_DP
PA13.Signal=SYS_JTMS-SWDIO
PA14.Signal=SYS_JTCK-SWCLK
PA15.Signal=S_TIM2_CH1_ETR
PA2.Signal=GPIO_Output
PA3.Signal=GPIO_Output
PA4.Signal=GPIO_Output
PA5.Signal=SPI1_SCK
PA6.Signal=SPI1_MISO
PA7.Signal=SPI1_MOSI
PA8.Signal=S_TIM1_CH1
PA9.Signal=USART1_TX
PB0.Signal=GPIO_Output
PB1.Signal=GPIO_Output
PB10.Signal=I2C2_SCL
PB12.Signal=GPIO_Output
PB13.Signal=SPI2_SCK
PB14.Signal=SPI2_MISO
PB15.Signal=SPI2_MOSI
PB2.Signal=GPIO_Output
PB3.Signal=GPIO_Output
PB4.Signal=S_TIM3_CH1
PB5.Signal=GPIO_Input
PB6.Signal=S_TIM4_CH1
PB7.Signal=GPIO_Input
PB8.Signal=CAN1_RX
PB9.Signal=CAN1_TX
PC0.Signal=GPIO_Output
PC1.Signal=GPIO_Output
PC10.Signal=USART3_TX
PC11.Signal=USART3_RX
PC12.Signal=I2C2_SDA
PC13.Signal=GPIO_Output
PC14-OSC32_IN.Signal=GPIO_Output
PC15-OSC32_OUT.Signal=GPIO_Output
PC2.Signal=GPIO_Output
PC3.Signal=GPIO_Output
PC4.Signal=GPIO_Output
PC5.Signal=GPIO_Output
PC6.Signal=S_TIM8_CH1
PC7.Signal=GPIO_Output
PC8.Signal=GPIO_Output
PC9.Signal=GPIO_Output
PD2.Signal=GPIO_Input
PH0-OSC_IN.Signal=RCC_OSC_IN
PH1-OSC_OUT.Signal=RCC_OSC_OUT

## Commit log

2026-07-26 Updated JOURNAL.md
    [voxboard.kicad_pcb, voxboard.kicad_sch]
2026-09-30 Major Update
    [voxboard.kicad_pcb]
2026-10-07 Clean up README by removing stage details and images
    Removed detailed descriptions of project stages and images.

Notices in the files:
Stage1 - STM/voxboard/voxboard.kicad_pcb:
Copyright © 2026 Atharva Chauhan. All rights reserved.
